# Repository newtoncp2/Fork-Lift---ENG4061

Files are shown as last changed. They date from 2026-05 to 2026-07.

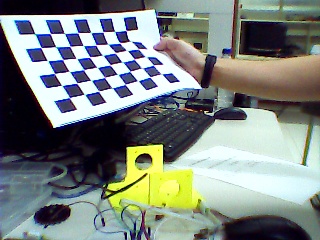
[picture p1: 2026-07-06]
python/camera_calibration/calibration_images/captured_image21.jpg

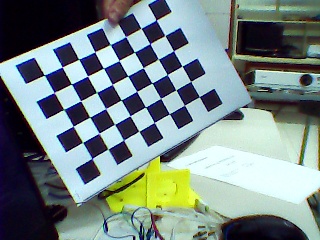
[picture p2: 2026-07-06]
python/camera_calibration/calibration_images/captured_image7.jpg

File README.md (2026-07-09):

# Robotic Forklift

> **Final Project for ENG4061 - Projeto de Robótica at PUC-Rio.**

This repository contains the documentation, source code, 3D models, and assembly instructions for an autonomous and teleoperated Robotic Forklift. The primary objective of the robot is to safely pick up, transport, and move a palletized payload of up to **0.5 kg** from one shelf to another.



## Key Features

The forklift operates in two distinct modes, seamlessly integrating mechanical robustness with advanced control systems:

* **Manual Mode (Teleoperation):** The robot can be manually controlled via a dedicated Web Server. This allows a human operator to drive the robot and operate the forklift mechanism remotely through a browser interface.

* **Autonomous Mode:** The robot is capable of autonomous navigation to move pallets between designated shelves without human intervention.

* **Computer Vision (AprilTags):** In autonomous mode, the robot uses a camera to detect AprilTags placed in the environment (e.g., on shelves or pallets) for precise spatial referencing, localization, and alignment.

* **PID Control:** A custom PID (Proportional-Integral-Derivative) control system ensures smooth, accurate, and stable locomotion when driving and aligning with the target shelves.

## System Architecture

To handle both high-level processing (vision and web server) and low-level hardware control, the system uses a dual-microcontroller architecture.

### Hardware Stack

* **High-Level Processing:** Raspberry Pi 3 (Handles the Web Server, camera input, and AprilTag detection).
* **Low-Level Control:** Arduino (Handles motor drivers, PID calculations, and sensor reading).
* **Locomotion:** 2x LEGO NXT Motors (Used for reliable differential drive locomotion).
* **Lifting Mechanism:** 1x NEMA 17 Stepper Motor paired with 6mm linear guides and LM6UU bearings for the vertical mast.

### Software Stack

* **Concurrency:** The Raspberry Pi script uses a mix of `threading` (for blocking serial reads/writes) and `asyncio` (for WebSocket streaming) with thread-safe queues.
* **Computer Vision:** OpenCV and AprilTag pipeline.
* **Communication Protocol:** * MQTT (with TLS encryption) to handle telemetry and command payloads.
  * WebSockets (`websockets` library) to stream real-time video feed frames directly to the Flask dashboard.
  * Serial Communication to relay movement commands to the Arduino.
 
## Telemetry & Monitoring (Grafana)

To monitor the robot's health and performance in real-time, a telemetry pipeline was built using a **PostgreSQL** database and a **Grafana** dashboard. 

This setup allows operators to track critical system metrics during both manual and autonomous operations:
* **Power Consumption:** Real-time monitoring of Voltage (V), Current (mA), and overall Power (mW).
* **Locomotion:** Live RPM tracking for both the left and right LEGO NXT motors.
* **System Status:** Live display of the current operational state (Manual, Autonomous, Search, Aligning) and immediate alerts for Stepper Motor failures.



> **Import the Dashboard:** The raw JSON template for this dashboard is available in [`telemetry/telemetry_grafana.json`](telemetry/telemetry_grafana.json). You can import it directly into your own Grafana instance to replicate this monitoring setup.

## Repository Structure

Navigate through the folders below to explore the specific modules of this project:

* `/mechanics` - Contains 3D CAD files (.STEP, .STL) and mechanical documentation.
  * **Read the [Mechanical Assembly & Troubleshooting Guide](mechanics/assembly.md)** for details on the Center of Mass, 3D printing parameters, and structural problem-solving.

* `/arduino` - Low-level motor control and PID implementation.
* `/python/raspberry_pi` - Web server, AprilTag vision system, and serial communication scripts.
* `/python/server` - Flask web server and MQTT broker configuration.
* `/electronics` - Additional schematics, wiring diagrams, and project reports.
* `/telemetry` - Contains the Grafana dashboard JSON template.

*Developed as an academic project for PUC-Rio.

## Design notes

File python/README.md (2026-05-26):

Fork-Lift AprilTag Detection (Python)
=================================

Overview
--------
This project detects AprilTags from a webcam feed, estimates each tag pose, and overlays:
- Tag outline and ID
- Distance (cm)
- Pitch angle (degrees)
- 3D pose axes (X, Y, -Z)

For every detected tag, the script also prints one line to the console:
id, x, y, z, pitch

Project Files
-------------
- apriltag.py
  Main application loop. Loads camera calibration, captures webcam frames, detects tags, draws overlays, and prints pose values.

- drawing.py
  Helper functions:
  - process_image(frame, tag): draws text/contours and returns pitch
  - draw_pose(overlay, camera_params, tag_size, pose): draws 3D axes

- requirements.txt
  Python dependencies.

- camera_calibration/
  Folder containing camera calibration utilities and outputs. It includes scripts used to capture calibration images and compute intrinsics, and stores the generated `camera_matrix.npy` and `dist_coeffs.npy`.

    - camera_matrix.npy
        Camera intrinsic matrix used for undistortion and pose estimation.

    - dist_coeffs.npy
        Camera distortion coefficients used for undistortion.

Requirements
------------
- Python 3.10+ (recommended)
- A connected webcam
- An AprilTag from family tag25h9

Install (Windows PowerShell)
-----------------------------
From this folder (`python`), run:

    python -m venv .venv
    .\.venv\Scripts\Activate.ps1
    python -m pip install --upgrade pip
    python -m pip install -r requirements.txt

Run
---
    python .\apriltag.py

Controls
--------
- Press `q` in the video window to quit.

Output
------
Console output example:
    id:3,x:12.4,y:-1.8,z:45.9,pitch:7.2

Notes
-----
- Coordinates are printed in centimeters (pose translation multiplied by 100).
- `tag_size` is currently set to 0.05 (meters) in `apriltag.py`.
  Update it if your physical tag has a different size.
- Detection is configured for family `tag25h9`.
- If your camera is not index 0, change `cv2.VideoCapture(0)` in `apriltag.py`.

Troubleshooting
---------------
1) No camera image
   - Close apps using the webcam.
   - Try another index in `cv2.VideoCapture(...)`.

2) Bad pose/distance estimates
   - Recheck `camera_matrix.npy` and `dist_coeffs.npy`.
   - Confirm `tag_size` matches your real tag size in meters.

3) No tags detected
   - Ensure the printed tag belongs to family `tag25h9`.
   - Improve lighting and keep the tag in focus.

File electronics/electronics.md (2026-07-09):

# Electronics & Wiring Architecture

This document outlines the hardware architecture, power distribution, and telemetry sensors used in the Robotic Forklift. The system relies on a dual-microcontroller setup to separate high-level computational tasks from low-level real-time hardware control.

## 1. Microcontrollers & Communication

The core of the robot operates on a Master-Slave architecture:
* **Raspberry Pi 3 (Master):** Handles the web server, WebSocket video streaming, and AprilTag computer vision processing. Operates at 3.3V logic.
* **Arduino MEGA 2560 (Slave):** Handles real-time PID motor control, stepper pulses, and sensor polling. Operates at 5V logic.
* **Logic Level Shifter (4CH):** Essential for safe Serial communication (TX/RX) between the Raspberry Pi and the Arduino, stepping the 3.3V signals up to 5V and vice versa to prevent pin damage.

## 2. Power Management

The robot is powered by an autonomous battery system, stepped down to meet the specific requirements of each component:
* **Power Source:** A 3S 18650 Li-ion battery pack (nominally 11.1V, up to 12.6V fully charged).
* **BMS (Battery Management System):** An HX-3S-FL10 module ensures safe charging/discharging and cell balancing.
* **Voltage Regulation:**
  * **U12 (XL4015 Buck Converter):** Steps down the battery voltage to a stable **5V** to power the Raspberry Pi 3 via Micro USB.
  * **U10 (XL4015 Buck Converter):** Steps down the battery voltage to a safe level (typically 7V-9V) to power the Arduino Mega via the P4 Barrel Jack.

## 3. Motor Drivers & Actuators

* **Locomotion (NXT Motors):** Driven by an **L298N** Dual H-Bridge motor driver. It takes PWM signals from the Arduino to control the speed and direction of the differential drive system.
* **Forklift Mast (NEMA 17):** Driven by a **DRV8825** stepper motor driver. Configured with a 47uF decoupling capacitor on the VMOT line to protect against voltage spikes. The `DIR` and `STEP` pins are controlled directly by the Arduino.

## 4. Telemetry & Sensors

To feed the Grafana Dashboard with real-time health data, the system includes dedicated monitoring hardware:
* **INA219 (Voltage & Current Sensor):** Connected via I2C (`SCL`/`SDA`) to the Arduino Mega. It measures the real-time current draw and voltage of the battery pack, allowing the calculation of the overall power consumption (mW).

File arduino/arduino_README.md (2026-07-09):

# Arduino Low-Level Control (Firmware)

This directory contains the firmware for the Arduino MEGA 2560, which acts as the low-level hardware controller (Slave) in the master-slave architecture. 

While the Raspberry Pi handles computer vision and path planning, this Arduino is strictly responsible for real-time operations: executing the PID control loop for locomotion, driving the NEMA 17 stepper motor, reading quadrature encoders via hardware interrupts, and polling telemetry sensors.

## Dependencies

To compile and upload this code, you must install the following libraries via the Arduino IDE Library Manager:
* **`Encoder`** (by Paul Stoffregen) - For high-speed hardware interrupt encoder reading.
* **`Adafruit_INA219`** - For polling the voltage and current sensor.
* **`ArduinoJson`** (v6 or v7) - For serializing telemetry data into JSON format.

## Operating Modes & Serial Protocol

The Arduino receives commands from the Raspberry Pi via Serial communication (Baud Rate: 115200). The command string is formatted as `<MODE> <PARAM1>,<PARAM2>\n`.

The firmware processes 4 distinct operational modes:

| Mode | Type | Syntax Example | Description |
| :--- | :--- | :--- | :--- |
| **`0`** | **Manual (Teleoperation)** | `0 100,-100\n` | Expects target RPMs for the Left and Right motors, respectively. Used for manual joystick control. |
| **`1`** | **Autonomous (Rotate)** | `1 1.57\n` | Expects a target angle `theta` (in radians). Calculates the required encoder pulses and applies opposite RPMs to pivot the robot in place. |
| **`2`** | **Autonomous (Forward)** | `2 0.5\n` | Expects a target distance `rho` (in meters). Calculates the required encoder pulses and applies equal RPMs to drive straight. |
| **`3`** | **Forklift Mast** | `3 50\n` | Expects a target position percentage (-100 to 100). Translates the percentage into stepper pulses using the `KS` (Step Gain) multiplier. |

> **Note on Autonomous Callbacks:** In modes 1 and 2, once the target number of encoder pulses is reached, the Arduino automatically stops the motors and sends a `fim modo X` string back to the Raspberry Pi to advance the higher-level State Machine.

## Control System Architecture

### 1. Locomotion Kinematics
The code uses hardcoded physical measurements of the robot to translate high-level spatial commands (radians and meters) into wheel rotations:
* **Wheelbase (`L`):** 0.195 meters.
* **Wheel Radius (`R`):** 0.027 meters.
* **Max RPM:** Capped at 150 RPM to ensure torque stability.

### 2. PID Control Loop
The main loop executes a closed-loop PID controller every `Ts` (20 milliseconds). 
* It calculates the current RPM of each wheel using the hardware encoders.
* Compares it to the target RPM to generate an error value.
* Applies Proportional (`KP`), Integral (`KI`), and Derivative (`KD`) gains to adjust the PWM output sent to the L298N driver. *(Note: KI and KD are currently zeroed out, relying on purely Proportional tuning `0.7 * KU`)*.

## Hardware Safety Features

The firmware includes several safety constraints to protect both the robot's structure and its electronics:

1. **Stepper Motor Fault Detection (`FLT` Pin):**
   If the DRV8825 driver detects a thermal shutdown or overcurrent event, it pulls the `FLT` pin LOW. The Arduino immediately intercepts this, stops the drive motors (ENA and ENB to 0), and disables the stepper driver.
2. **Mast Endstop Interlock (`B2` Pin):**
   During Mode 3 (Mast operation), the firmware continuously checks the tactile button at the top of the mast. If the button is triggered (`LOW`) while the motor direction is set to UP, the stepping loop is instantly aborted to prevent the 3D-printed carriage from crashing into the frame.
3. **Battery Undervoltage Protection:**
   The INA219 sensor is polled periodically. If the bus voltage drops below **9.7V**, the Arduino sends a "shutdown command" warning over Serial to prevent deep-discharging and permanently damaging the 3S Li-ion battery pack.

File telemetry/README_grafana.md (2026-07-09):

# Telemetry Dashboard - rb_telemetria

This file (`telemetry_grafana.json`) defines a Grafana dashboard (`dashboard.grafana.app/v2` format) responsible for displaying real-time telemetry data from the project's autonomous forklift. It can be imported directly into Grafana to recreate the monitoring panel.

## Overview

- **Dashboard Title:** `rb_telemetria`
- **Data Source:** PostgreSQL/TimescaleDB (datasource `efr0zsd6jbvnke`), dataset `projeto_b`
- **Queried Table:** `rb_emp`
- **Default Time Range:** Last 5 minutes (`now-5m` to `now`)
- **Available Auto-refresh:** 5s, 10s, 30s, 1m, 5m, 15m, 30m, 1h, 2h, 1d (no fixed interval is applied by default)
- **Timezone:** Browser's timezone

## Panels

| Panel | Title | Type | Source Column | Calculation/Query | Range (min-max) |
|---|---|---|---|---|---|
| panel-1 | Voltage | gauge | `tensao_v` | Average per 1s bucket | 11 to 12.4 |
| panel-2 | Current | gauge | `corrente_ma` | Average per 1s bucket | 0 to 3 |
| panel-3 | Power | gauge | `potencia_mw` | Average per 1s bucket | 0 to 37.2 |
| panel-4 | Left RPM | gauge | `rpm_esq` | Average per 1s bucket | 0 to 150 |
| panel-5 | Right RPM | gauge | `rpm_dir` | Average per 1s bucket | 0 to 150 |
| panel-6 | Mode | stat | `tipo` | Latest reading (`ORDER BY created_at DESC LIMIT 1`) | - |
| panel-7 | Stepper Motor Failure? | stat | `falha_motor_passo` | Latest reading (`ORDER BY created_at DESC LIMIT 1`) | - |

### Panels 1 to 5 (Time Series Gauges)

These panels use TimescaleDB's `time_bucket('1 second', created_at)` to aggregate data into 1-second windows and calculate the average (`AVG`) of the corresponding column within the time range selected on the dashboard (`$__timeFilter(created_at)`). All of them display a sparkline and use a continuous color gradient (green to red), except Current and Right RPM, which use percentage-based thresholds (60% yellow, 80% red).

### Panel 6 - Mode

Displays the system's current operation mode, translating the numerical value from the `tipo` column into a textual label:

- `0` -> Manual
- `1` -> Autonomous
- `2` -> Search
- `3` -> Fork
- Any other value -> Unknown

### Panel 7 - Stepper Motor Failure?

Displays the latest status from the `falha_motor_passo` column, translated into text:

- `0` -> No
- `1` -> Yes
- Any other value -> Unknown

## Screen Layout

The panels are organized in a 22-column grid, across three rows:

1. **Row 1** (height 6): Voltage, Current, and Power side by side.
2. **Row 2** (height 6): Stepper Motor Failure, Left RPM, and Right RPM side by side.
3. **Row 3** (height 4): Mode, taking up the full width (22 columns).

## Reusability Requirements

For this dashboard to work in another environment, the following is required:

1. A Grafana instance (Cloud or self-hosted) compatible with the `dashboard.grafana.app/v2` schema.
2. A configured `grafana-postgresql-datasource` pointing to the PostgreSQL/TimescaleDB database that contains the `projeto_b` dataset and the `rb_emp` table.
3. Update the `datasource.name` field in each panel (`efr0zsd6jbvnke`) to match the UID of the datasource configured in the new environment, if different.
4. Ensure the `rb_emp` table has at least the following columns: `created_at`, `tensao_v`, `corrente_ma`, `potencia_mw`, `rpm_esq`, `rpm_dir`, `tipo`, and `falha_motor_passo`.

## Importing into Grafana

1. In Grafana, go to **Dashboards > New > Import**.
2. Paste the contents of `telemetry_grafana.json` or upload the file.
3. Select or adjust the corresponding PostgreSQL datasource.
4. Confirm the import.

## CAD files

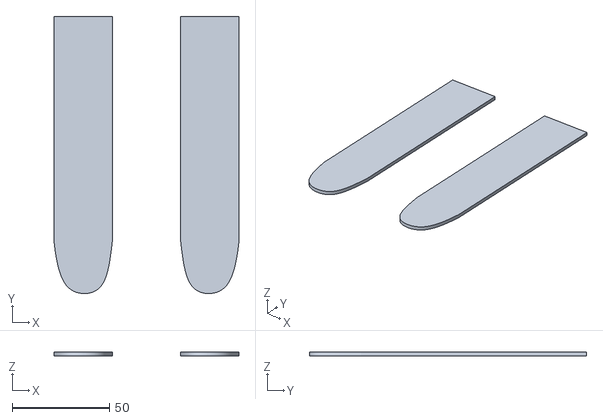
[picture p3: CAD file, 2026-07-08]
mechanics/cad/fork_extension.stl
95.0 x 142.3 x 2.00

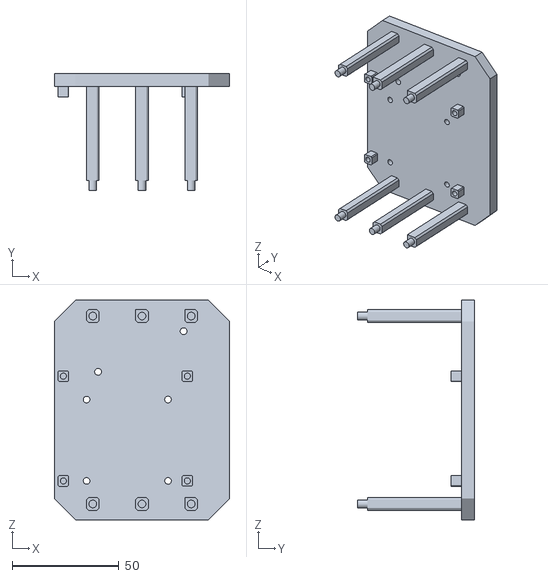
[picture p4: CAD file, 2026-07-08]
mechanics/cad/second_floor_annex.stl
82.0 x 54.7 x 102.9

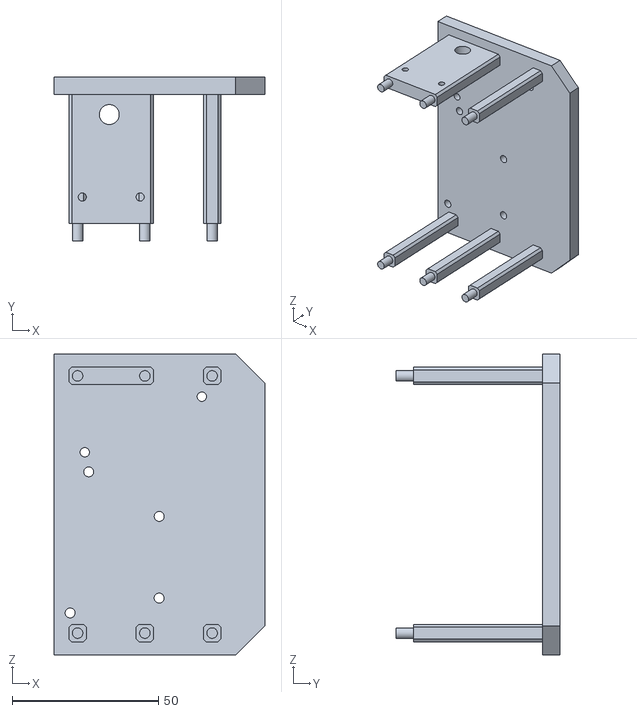
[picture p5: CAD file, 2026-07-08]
mechanics/cad/first_floor_annex.stl
72.0 x 56.0 x 102.9

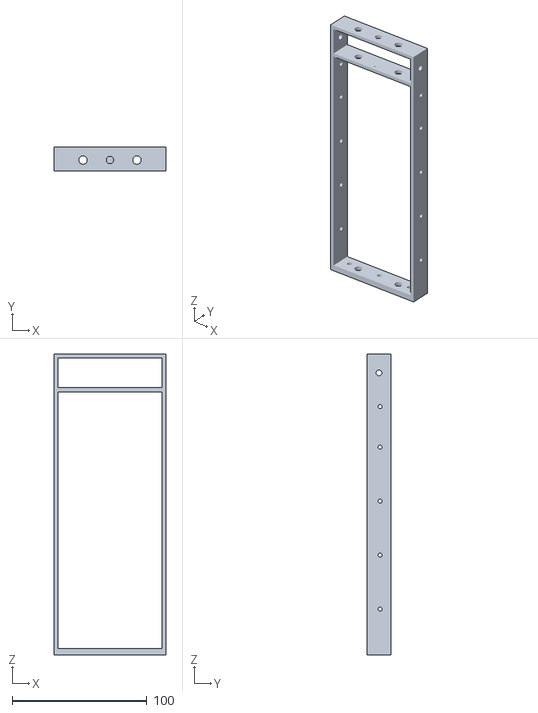
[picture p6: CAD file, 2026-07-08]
mechanics/cad/frame.stl
82.9 x 17.5 x 223.0

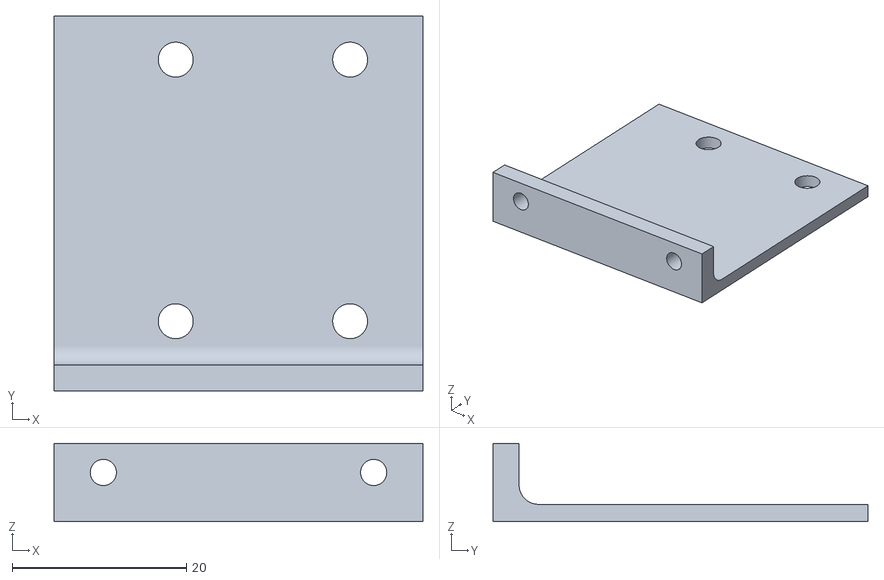
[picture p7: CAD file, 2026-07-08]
mechanics/cad/nema17_support.stl
42.3 x 43.0 x 9.00

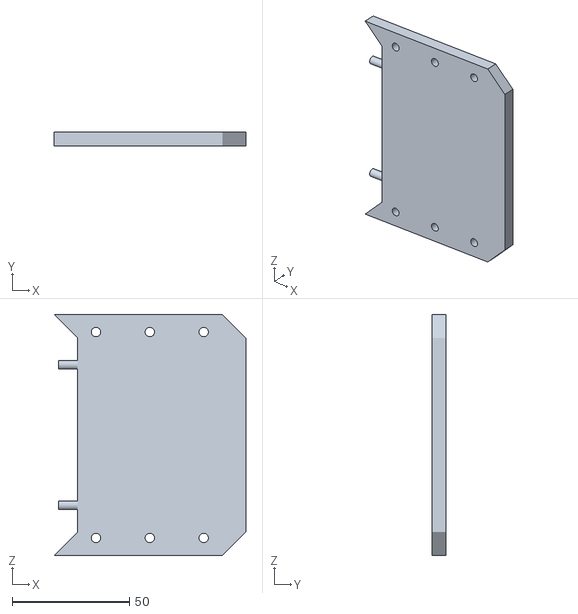
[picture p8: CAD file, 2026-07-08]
mechanics/cad/base_eletronics_annex.stl
81.9 x 6.00 x 102.9

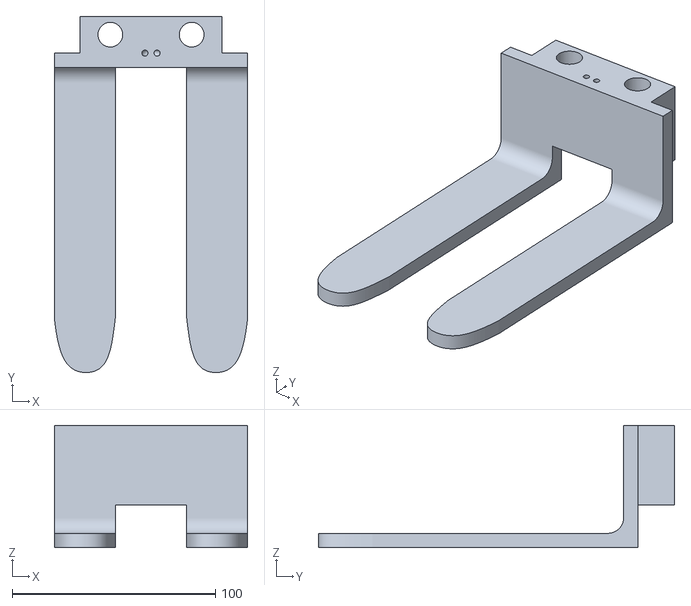
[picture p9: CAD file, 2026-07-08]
mechanics/cad/fork.stl
95.0 x 175.0 x 60.0

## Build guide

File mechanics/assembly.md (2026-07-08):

# Mechanical Assembly & Troubleshooting

This document details the mechanical assembly process, structural decisions, and field modifications made to ensure the robotic forklift met the 0.5 kg payload requirement safely and efficiently.

## 1. CAD & 3D Printing Guidelines

All custom parts were designed in Onshape. When printing the structural components (especially the main mast and forks), layer orientation is critical to withstand bending moments.

* **Utilizaed Printer:** Bambu Lab A1
* **Material:** PETG or high-quality PLA (PETG preferred for impact resistance).
* **Infill:** At least 30-40% (Gyroid or Cubic pattern) for the fork and mast components.
* **Orientation:** Print the forks laying flat on the build plate to ensure the layer lines run parallel to the load direction, preventing delamination.

> **Note:** The CAD files (`.STEP` and `.STL`) can be found in the `/cad` folder.

## 2. Base Chassis & Center of Mass

To prevent the forklift from tipping forward when lifting the 0.5 kg payload, the center of gravity (CG) was carefully managed:

* **NEMA 17 Placement:** The NEMA 17 stepper motor is mounted in the geometric center of the chassis. This centralizes the mass and acts as a structural anchor.
* **Counterweight Box:** The elongated blue and orange enclosure (shown in the image below) at the rear of the robot houses the electronics and acts as a physical ballast. This counterweight keeps the CG safely within the wheelbase.

WhatsApp Image 2026-06-04 at 22 33 42

## 3. Mast & Linear Motion

The vertical lift system relies on a rigid and smooth linear motion setup. Assembly order is critical here to avoid binding or breaking the 3D printed parts:

* First, press-fit or mount the **6mm linear bearings (LM6UU)** securely into their housings on the fork carriage.
* Insert the **6mm linear guide rods** into the bottom mounts of the main frame.
* Carefully slide the assembled fork carriage (with the pre-installed bearings) down onto the guide rods.
* Finally, cap the top of the mast to lock the rods in place, ensuring they are perfectly parallel to prevent binding during manual operation.

## 4. Safety Interlock System

Since the forklift operates via manual open-loop control, a hardware safety measure was implemented to prevent structural damage.
* **Endstop Switch:** Mount the tactile limit switch at the very top of the mast.
* **Function:** This acts as a mechanical interlock. If the operator attempts to raise the fork beyond the maximum height, the fork triggers the switch, instantly cutting power to the NEMA 17 motor.

## 5. Field Modifications & Troubleshooting

During physical testing, the gap between theoretical CAD and the real world required a few immediate engineering solutions:

### A. Load Slipping (Friction Issue)
* **Problem:** The 3D printed surface of the forks was too smooth, causing the pallet to slide off during movement.
* **Solution:** Drops of hot glue were strategically applied to specific contact points on the forks. This significantly increased the static friction coefficient, locking the pallet in place.

### B. Frame Bending (Structural Rigidity)
* **Problem:** The frame holding the linear guides only had three support points. Under load, the structure would yield and tilt upward.
* **Solution:** Instead of redesigning and enlargening the structure, holes were designed into the frame and tensioned ropes were attached. These ropes act as tensile trusses, rigidifying the entire mast assembly and eliminating the tilt.

### C. Z-Axis Tolerance (Shelf Clearance)
* **Problem:** The maximum Z-height of the forks was designed with very tight tolerances. When fully loaded, it struggled to clear the shelf height for pallet placement.
* **Solution:** Two custom extension attachments were designed and 3D printed. These snap onto the existing forks, providing the extra Z-height clearance needed for smooth operation without modifying the main mast.

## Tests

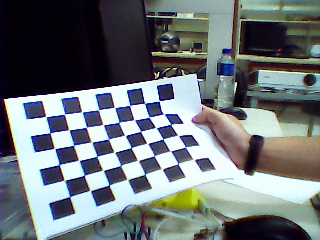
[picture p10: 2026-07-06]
python/camera_calibration/calibration_images/captured_image22.jpg

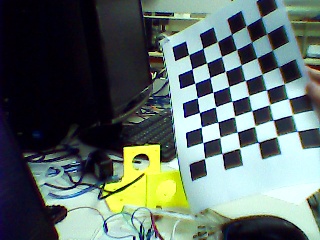
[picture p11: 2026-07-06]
python/camera_calibration/calibration_images/captured_image8.jpg

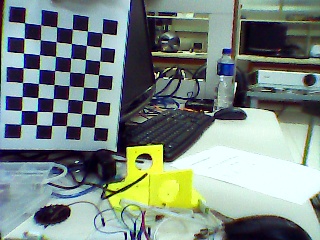
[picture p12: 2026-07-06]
python/camera_calibration/calibration_images/captured_image16.jpg

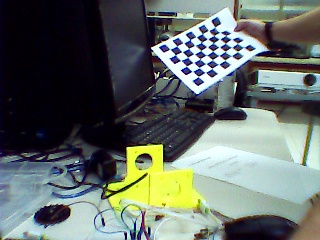
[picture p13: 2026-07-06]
python/camera_calibration/calibration_images/captured_image20.jpg

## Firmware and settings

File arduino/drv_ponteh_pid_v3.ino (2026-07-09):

#define ENCODER_OPTIMIZE_INTERRUPTS
#include <Encoder.h>
#include <Adafruit_INA219.h>
#include <ArduinoJson.h>

#define IN1 52
#define IN2 50
#define IN3 48
#define IN4 42
#define ENA 46
#define ENB 44

#define DIR 45
#define RS 49
#define EN 51
#define STP 47
#define FLT 53

#define B1 31
#define B2 35

#define KU 8
#define TU 0.125  // em s

#define KP (0.7 * KU)
#define KI 0 //(0.2*KU/TU) //(1.2 * KU / TU)
#define KD 0 //(0.04 * KU * TU)

#define KV (0.4 / 0.8)  // v_desejada / rho_tipico => setpoint de vel linear do robô e distância típica de detecção, algo entre 0.5m e 1m talvez? AJUSTAR
#define KW (5 * KV)     // normalmente entre 2KV e 3KV AJUSTAR

#define Ts 20

#define PI 3.1415926535897932384626433832795

Encoder encoderD(2, 3);
Encoder encoderE(19, 18);

Adafruit_INA219 INA;

const int DELAY_US = 200;
const int KS = 122;  // "ganho de step" : servidor envia 0 - 100 , motor gira 12200 passos da base ao topo

bool girar = false;
bool no_topo = false;
int passos_a_girar = 0;
int passos_girados = 0;

unsigned long instanteAnterior = 0;
unsigned long instanteAnterior2 = 0;

int modo = 0;

float rho = 0;
float theta = 0;
int pulsos = 0;

const float L = 0.195;                      // distância entre o meio das rodas em m (medido: 0.1722 m , melhor correção : )
const float R = 0.027;                      // raio da roda em m (medido: 0.02823 m , melhor correção : 0.027 m)
const float rpm_max = 150;                  // em rpm (obviamente??)
const float v_max = rpm_max * PI * R / 30;  // em m/s
const float w_max = 2 * v_max / L;
 
float rpm_e_temp, rpm_d_temp, v, w;

long inicial_e_auto = 0;
long inicial_d_auto = 0;

long atual_e = 0;
long atual_d = 0;

long inicial_e = 0;
long inicial_d = 0;

float rpm_desired_e = 0;
float rpm_desired_d = 0;

float rpm_e = 0;
float rpm_d = 0;

float error_e = 0;
float error_e_ant = 0;
float error_d = 0;
float error_d_ant = 0;

float prop_e = 0;
float int_e = 0;
float der_e = 0;
float prop_d = 0;
float int_d = 0;
float der_d = 0;

void enviarTelemetria(float tensao, float corrente, float potencia, bool falha_motor_passo, int rpm_e, int rpm_d) {
  JsonDocument msg;
  msg["tipo"] = "m";
  msg["falha_motor_passo"] = falha_motor_passo;
  msg["tensao_V"] = tensao;
  msg["corrente_mA"] = corrente;
  msg["potencia_mW"] = potencia;
  msg["rpm_esq"] = rpm_e;
  msg["rpm_dir"] = rpm_d;
  msg["t_ms"] = millis();

  serializeJson(msg, Serial);
}

void move_garfo() {
  digitalWrite(STP, HIGH);
  delayMicroseconds(DELAY_US);
  digitalWrite(STP, LOW);
  delayMicroseconds(DELAY_US);
}

void configura_ponteH(int motor_e, int motor_d) {
  if (motor_e <= 0) {
    digitalWrite(IN4, HIGH);
    digitalWrite(IN3, LOW);
  } else {
    digitalWrite(IN4, LOW);
    digitalWrite(IN3, HIGH);
  }

  if (motor_d <= 0) {
    digitalWrite(IN1, HIGH);
    digitalWrite(IN2, LOW);
  } else {
    digitalWrite(IN1, LOW);
    digitalWrite(IN2, HIGH);
  }
}

void move_robo_PID() {
  float saida_e = KP * prop_e + KI * int_e + KD * der_e;
  saida_e = constrain(saida_e, -255, 255);

  float saida_d = KP * prop_d + KI * int_d + KD * der_d;
  saida_d = constrain(saida_d, -255, 255);
  
  configura_ponteH(saida_e, saida_d);

  analogWrite(ENA, abs(saida_d));
  analogWrite(ENB, abs(saida_e));

  //Serial.print("saida_e:"); Serial.print(String(rpm_e)); Serial.print(","); Serial.print("saida_d:"); Serial.print(String(rpm_d)); Serial.print(","); Serial.print("fixo:"); Serial.println(200);
  //analogWrite(ENA, abs(rpm_desired_d)); analogWrite(ENB, abs(rpm_desired_e));  //modo sem PID
}

void procura_apriltag() {
  Serial.println("NAO ME IGNORE ME IMPLEMENTE POR FAVOR ME IMPLEMENTE :(");
}

void setup() {
  Serial.begin(115200);

  // pinos de alimentação de sensores
  pinMode(40, OUTPUT);
  pinMode(36, OUTPUT);
  pinMode(17, OUTPUT);
  pinMode(16, OUTPUT);
  pinMode(15, OUTPUT);
  pinMode(14, OUTPUT);
  pinMode(5, OUTPUT);
  pinMode(4, OUTPUT);

  digitalWrite(40, HIGH);
  digitalWrite(17, HIGH);
  digitalWrite(14, HIGH);
  digitalWrite(4, HIGH);

  digitalWrite(36, LOW);
  digitalWrite(16, LOW);
  digitalWrite(15, LOW);
  digitalWrite(5, LOW);

  //pinos do DRV
  digitalWrite(EN, LOW);   // ativo-baixo, LOW = habilitado
  digitalWrite(RS, HIGH);  // RST e SLP ativo-baixo
  digitalWrite(DIR, LOW);  // LOW = sobe
                           // M0 M1 M2 = 0 0 0 (flutuando) := modo full step (atualmente, M2 em curto com RS então modo 1/16)

  pinMode(EN, OUTPUT);
  pinMode(RS, OUTPUT);
  pinMode(DIR, OUTPUT);
  pinMode(STP, OUTPUT);
  pinMode(FLT, INPUT_PULLUP);  // quando digitalRead(FLT) = LOW, DRV sinalizou falha no motor

  //controle da ponteH
  pinMode(IN1, OUTPUT);
  pinMode(IN2, OUTPUT);
  pinMode(ENA, OUTPUT);
  pinMode(IN3, OUTPUT);
  pinMode(IN4, OUTPUT);
  pinMode(ENB, OUTPUT);

  //fim de curso
  pinMode(B1, OUTPUT);
  pinMode(B2, INPUT_PULLUP);
  digitalWrite(B1, LOW);

  Wire.begin();
  if (!INA.begin()) {
    //Serial.println("Could not connect. Fix and Reboot");
  }

  INA.setCalibration_32V_2A();
}

void loop() {
  if (!digitalRead(FLT)) {
    analogWrite(ENA, 0);
    analogWrite(ENB, 0);

    digitalWrite(EN, HIGH);
  } else {
    if (Serial.available()) {
      String input = Serial.readStringUntil('\n');
      Serial.println("Recebi: " + input);

      modo = input.substring(0, 1).toInt();
      int i = input.indexOf(',');

      // se der bom, mover encoder.write(0) e atual = 0 pra cá, se der ruim, remover
            
      switch (modo) {
        case 0:  // modo manual
          encoderE.write(0);
          encoderD.write(0);
          atual_e = 0;
          atual_d = 0;
          rpm_e_temp = input.substring(2, i).toFloat();
          rpm_d_temp = input.substring(i + 1).toFloat();
          break;
        case 1:  // modo autônomo - giro no mesmo eixo
          encoderE.write(0);
          encoderD.write(0);
          atual_e = 0;
          atual_d = 0;
          theta = input.substring(2, i).toFloat();
          theta = constrain(theta, -2*PI, 2*PI);
          if (abs(theta) < 0.2) {theta = 0; int_e = 0; int_d = 0;}; // evita PWM ultra fraco e contagem inalcançável de pulsos

          pulsos = (abs(theta) * 720.0 * L) / (4 * PI * R);

          w = constrain(KW * theta, -w_max, w_max);
          
          rpm_e_temp = -(w * L / 2) * 30 / (PI * R); // - : angulo positivo = giro pra esquerda
          rpm_d_temp = (w * L / 2) * 30 / (PI * R);  // - : angulo positivo = giro pra direita

          break;
        case 2:  // modo autônomo - andar pra frente
          encoderE.write(0);
          encoderD.write(0);
          atual_e = 0;
          atual_d = 0;
          rho = input.substring(2, i).toFloat();
          rho = constrain(rho, -2, 2);

          if (abs(rho) < 0.03) {rho = 0; int_e = 0; int_d = 0;}; // evita PWM ultra fraco e contagem inalcançável de pulsos

          pulsos = (abs(rho) * 720.0) / (4 * PI * R);

          inicial_e_auto = 0;
          inicial_d_auto = 0;

          v = constrain(KV * rho, -v_max, v_max);

          rpm_e_temp = v * 30 / (PI * R);
          rpm_d_temp = v * 30 / (PI * R);

          break;
        case 3:  // modo de controle do garfo ()
          girar = true;
          passos_girados = 0;
          passos_a_girar = constrain(input.substring(2).toInt(), -100, 100) * KS;
  
          if (passos_a_girar <= 0) {
            digitalWrite(DIR, HIGH);
            passos_a_girar *= -1;
          } else {
            digitalWrite(DIR, LOW);
          }
          break;

        default:
          break;
      }

      rpm_desired_e = (float)constrain(rpm_e_temp, -rpm_max, rpm_max);
      rpm_desired_d = (float)constrain(rpm_d_temp, -rpm_max, rpm_max);
      //Serial.println("RPM_E: " + String(rpm_desired_e) + ", RPM_D: " + String(rpm_desired_d));
    }

    if (girar){
        if (passos_a_girar == passos_girados) {
          passos_a_girar = 0;
          passos_girados = 0;
          Serial.println("fim modo 3");
          modo = 0;
          girar = false;
      } else {
        no_topo = digitalRead(B2);
        
        if (!no_topo || (no_topo && digitalRead(DIR))) {
          move_garfo();
          passos_girados++;
        } else {
          passos_girados = passos_a_girar;
        }
      }
    }
    
    unsigned long instanteAtual = millis();
    if (instanteAtual - instanteAnterior > Ts) {
      double dt = (instanteAtual - instanteAnterior) / 1000.0f;
      instanteAnterior = instanteAtual;

      atual_d = encoderD.read();

      long dif_d = atual_d - inicial_d;
      rpm_d = (float)dif_d * 6000.0f / (72.0f * dt * 1000.0f);

      atual_e = encoderE.read();

      long dif_e = atual_e - inicial_e;
      rpm_e = (float)dif_e * 6000.0f / (72.0f * dt * 1000.0f);

      inicial_e = atual_e;
      inicial_d = atual_d;

      error_e = rpm_desired_e - rpm_e;
      prop_e = error_e;
      int_e += abs(error_e) < 40 ? error_e * dt : 0;
      der_e = (error_e - error_e_ant) / dt;

      error_d = rpm_desired_d - rpm_d;
      prop_d = error_d;
      int_d += abs(error_d) < 40 ? error_d * dt : 0;
      der_d = (error_d - error_d_ant) / dt;

      error_e_ant = error_e;
      error_d_ant = error_d;

      //Serial.println("enc_e: " + String(atual_e) + " " + "enc_d: " + String(atual_d));
      move_robo_PID();
    }

    if (abs(atual_e) > pulsos && abs(atual_d) > pulsos && (modo == 1 || modo == 2)) {
      pulsos = 0;
      rpm_desired_d = 0;
      rpm_d_temp = 0;
      rpm_desired_e = 0;
      rpm_e_temp = 0;
      Serial.println("fim modo " + String(modo));

      modo = 0;
    }

    if (millis() - instanteAnterior2 > 1500) {
      if (INA.getBusVoltage_V() < 9.7){
        Serial.println("comando de shutdown");
      }
      //enviarTelemetria(INA.getBusVoltage_V(), INA.getCurrent_mA(), INA.getPower_mW(), !digitalRead(FLT), rpm_e, rpm_d);
      instanteAnterior2 = millis();
    }
  }
}

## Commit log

2026-05-26 Add AprilTag detection project with camera calibration and image capture functionality
2026-06-09 remove video display on raspberry
2026-06-09 feat: add serial communication for Arduino integration and distance calculation
2026-06-16 test: change uart to usb
2026-06-16 change opencv threads to 2
2026-06-16 send frames via websocket
2026-06-16 test calibrations
2026-06-30 calibrate z_coord
2026-07-01 only send msg when pressing buttons
2026-07-02 print do comando enviado pro arduino
2026-07-02 corrigir identação de else
2026-07-02 prints de debug
2026-07-02 testa sem condição de is.autonomous
2026-07-03 muda loggers pra prints
2026-07-03 ajustes de controle
2026-07-03 ajuste de angulos
2026-07-03 ajuste de valores
2026-07-04 Refatoração do controle, estruturação mais legível da máquina de estados, implementação de palletização autônoma, correção da lógica de aproximação (não volta pra busca se perde a tag no meio)
2026-07-05 optimize camera capture
2026-07-05 dont disconnect websocket every frame and add mutex operations in server
2026-07-06 print x0 e z0
2026-07-06 hardcode escala de leitura
2026-07-06 muda ID da camera
2026-07-06 id camera
2026-07-06 teste "0 0,0" no começo de aproximar
2026-07-07 assembly instructions
2026-07-08 Create database thread
2026-07-08 fix start database thread
2026-07-09 mudar para ingles
2026-07-09 Update electronics documentation formatting and content
    Removed schematic image and its caption from the document. Adjusted formatting for voltage regulation section and telemetry sensors.
2026-07-09 Create README for Arduino firmware documentation
    Added detailed firmware documentation for Arduino MEGA 2560, including dependencies, operating modes, control system architecture, and safety features.
